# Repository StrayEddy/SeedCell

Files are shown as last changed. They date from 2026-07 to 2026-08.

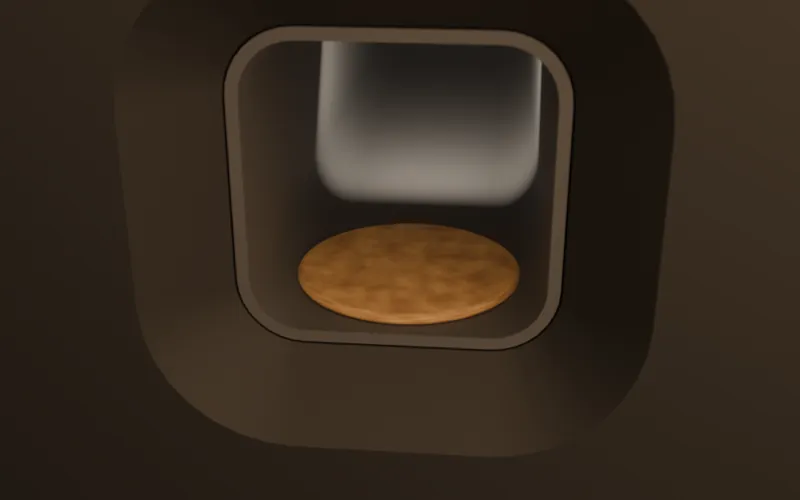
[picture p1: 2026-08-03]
assets/hero-800.webp

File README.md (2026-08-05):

# SeedCell

**🌐 Project site: [strayeddy.github.io/SeedCell](https://strayeddy.github.io/SeedCell/)**

**Autonomous public food infrastructure — the food sibling of [HiveCell](../HiveCell).**

> **Open-source hardware research — uncertified, not a deployable product.**
> SeedCell bakes and serves food to the public from an unattended machine. It is
> **design and simulation only**: no built hardware, no microbiological validation, no
> food-safety certification. **Do not build this to feed anyone.** See [`LICENSE`](LICENSE)
> for the full safety notice and licensing.

A public, autonomous machine that turns long-life dry ingredients into a fresh, warm,
nutritious flatbread on demand, so that **no one goes hungry because they cannot afford
food**. It is not a vending machine — it is closer to a **food syringe**: a sealed machine
that briefly opens, delivers food, then cleans itself.

Design priorities (in order): food safety & hygiene, vandal resistance, reliability, low
maintenance, low energy, low cost, simplicity, long lifetime. It guarantees basic
nutrition — a warm daily survival ration eaten by hand with no packaging — not a meal out.

## Mechanism

**The hot syringe (ADR-0001).** A single heated piston moves inside a fixed heated bore.
Idle, the piston face is the flush public wall. To make food it retracts to open a short
cook chamber; dry blend is metered in and **hydrated by injected water jets — no mixer
blade** (ADR-0006); the piston presses the dough and **conduction-bakes** it against its
heated face (ADR-0007); it advances to flush at the wall, leaving the flatbread standing
proud where a person can take it (ADR-0021); then parks deep
in a sealed zone to **scrape + steam + heat-sterilize + dry** before the next serving
(ADR-0010). The whole cycle is one part translating along one axis — the same syringe bargain
as HiveCell.

The engineering goal is not making food — it is **minimizing food-contact surfaces**. The
design collapses them to essentially one chamber, one transfer, one delivery surface: the
bore wall and the piston face. Everything upstream stays dry (ADR-0012).

## Food

A fortified protein flatbread from whole-wheat + chickpea + lentil flour, a little oil, salt,
water, and a micronutrient premix. Target per serving (`scripts/dosing.py`, first-order):

| Metric | Target | Model |
|---|---|---:|
| Energy | 500–700 kcal | ~571 kcal |
| Protein | 20–30 g | ~26 g |
| Ingredient cost | $0.15–0.25 | ~$0.21 |

Cook thermodynamics + energy in `scripts/cook_energy.py` (~59 Wh/serving bake).

## Safety status

SeedCell makes food for **vulnerable people, unattended, for years**, so food safety is the
first design constraint. Full analysis in [`docs/SAFETY.md`](docs/SAFETY.md); decisions in
[`docs/DECISIONS.md`](docs/DECISIONS.md). The core invariant: **a batch that is not provably
cooked AND served on a provably clean surface is diverted to waste, never to a person.**

Current state — **design + simulation / first-order analysis, no certified hardware:**

| Safety function | Status |
|---|---|
| SF1 Cook lethality (primary) | diverse-redundant fail-safe voter (2× core probe + IR + F-value), serve only on positive proof (ADR-0009) — `[sim]` |
| SF2 Surface sanitation (primary) | scrape + steam + reused-heat sterilize + dry, verify-or-lockout every cycle (ADR-0010) — `[sim/decision]` |
| SF3 Contamination barrier / scraper seal | circular scraper lips wipe the full bore each stroke; drag/residue budget (ADR-0011) — `[cad]` |
| SF4 Burn + pinch guard | touch-safe surface cap + mouth force cap → abort present (H4/H5) — `[sim]` |
| SF5 Motion signalling + soft profile | beacon + soft-start/stop + slow final approach (shared with HiveCell) — `[sim]` |
| SF6 Ingredient integrity / spoilage lockout | dry-storage moisture/temp lockout (ADR-0012) — `[decision]` |

**Biggest open risk:** food **residue + release** is the master variable — it couples the
cleaning method (SF2), the scraper (SF3), the surface + formula (ADR-0008), yet is only
estimated (~1000× range, `scripts/residue.py`). It must be measured on a real baked coupon
before the cleaning design is frozen (ADR-0011). A ~$150–250 bench procedure to do exactly
that — the highest-value next experiment, and a great first contribution — is in
[`docs/residue_bench_test.md`](docs/residue_bench_test.md).

## Software stack

| Tool | Role |
|---|---|
| FreeCAD  | Mechanical design (parametric, source of truth) |
| Godot | Process / food-safety simulation & digital twin |
| Blender  | Rendering & presentation (later only) |
| Git | Version control |

## Layout

- `cad/`     — FreeCAD model (generated by `scripts/build_model.py`)
- `docs/`    — engineering notes, calculations, decisions
- `scripts/` — parametric model + first-order analysis (dosing, cook, residue, sizing)
- `godot/`   — process digital twin + headless self-tests
- `docs/DECISIONS.md` — engineering decision log (read this first)
- `docs/SAFETY.md`   — food-safety + machine-safety analysis
- `docs/ROADMAP.md`  — prioritized roadmap

## Setup

The machine must never serve food that isn't provably safe, so the serve cycle is gated by a
food-safety interlock (`godot/process_interlock.gd`, per `docs/SAFETY.md`). A headless
self-test enforces the core invariant — a raw or unclean batch is never served — and a
pre-push hook blocks pushes if it fails.

After cloning, point git at the hook once:
```sh
git config core.hooksPath .githooks
```
Run the self-tests manually anytime (set `GODOT_BIN` if Godot isn't on `PATH`):
```sh
./scripts/run_selftest.sh
```
Regenerate the CAD model / run the analysis:
```sh
flatpak run --command=freecadcmd org.freecad.FreeCAD scripts/build_model.py
python3 scripts/dosing.py && python3 scripts/cook_energy.py && python3 scripts/residue.py
```

## License & contributing

SeedCell is open-source, licensed by file type: **hardware** (`cad/`, `blender/`,
`renders/`) under CERN-OHL-S-2.0; **documentation** (`docs/`, this README) under CC-BY-4.0;
**software** (`godot/`, `scripts/`) under Apache-2.0. Full texts in [`LICENSES/`](LICENSES/);
the scheme and **safety notice** are in [`LICENSE`](LICENSE). Contributions welcome — see
[`CONTRIBUTING.md`](CONTRIBUTING.md); the most valuable one right now is a real bench
measurement of food residue/release (ADR-0011).

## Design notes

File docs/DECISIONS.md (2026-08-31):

# Engineering Decision Log

Append-only record of significant engineering decisions (an ADR — Architecture
Decision Record — log). Each entry: what we decided, why, and what it rules out.
Newest at the bottom. SeedCell is the food analog of the sibling
[HiveCell](../../HiveCell) project and deliberately reuses its workflow and conventions.

---

## ADR-0001 — Motion principle: the hot syringe (cook-in-bore, eject-through-mouth)
**Date:** 2026-07-31
**Status:** Accepted

**Decision.** SeedCell is a single heated piston moving inside a fixed heated tube
("bore"), directly mirroring HiveCell's true-syringe topology — but the product is a
flatbread ejected through the mouth, not a cavity presented to a person.
- Idle: the piston face sits flush at the mouth (the public wall plane, X=0), sealing
  the machine. The face IS the flush public wall — no separate door or shutter.
- Make: the piston retracts, opening a short cook chamber in the bore; dry blend is
  metered in and hydrated in place; the piston presses the dough into a thin disc and
  bakes it against its own heated face. (*Written as two hot faces; only one exists —
  ADR-0017, open.*)
- Deliver: the piston advances to flush at the wall plane and stops there, leaving the
  finished flatbread standing 8 mm proud where a person can take it (ADR-0021).
- Clean: the piston parks deep in a sealed sterilize zone where its face and the bore
  are scraped, steamed, heat-sterilized and dried before the next serving.

**Why.** Fewest moving parts (one primary piston, one drive) → best reliability, cost,
simplicity — the same reasoning that made HiveCell a syringe. Crucially, it collapses
the **food-contact surfaces to the absolute minimum**: the bore wall and the piston
face — "one chamber, one transfer, one delivery surface" (the stated
design goal). The piston face does quadruple duty (flush wall + cook platen + delivery
surface + cleaning interface), exactly as HiveCell's piston is floor + door + squeegee.

**Rejected alternatives.**
- A — Conveyor/station line (dose → mix → press → griddle → deliver): a bakery in a
  box. Every transfer is another food-contact surface to clean; the opposite of the goal.
- B — Vending of pre-made items: not fresh, needs packaging, not the mission.
- C — Rotary drum / carousel of pans: most mechanism + many pans to clean.

**Accepted costs / constraints.** A few hidden service-side helpers may still be needed
(a mouth die, hydration jets, cleaning stations) — SeedCell will accrete them the way
HiveCell accreted spray rings and a service squeegee. *(2026-08-05: the mouth die was the
first of these to be tested against the rest of the design, and it did not survive — see
ADR-0021. Worth noting that this paragraph predicted accretion and named the exact part
that turned out to be unearned.)* The single-chamber ideal has a
real tension: charging + hydration ports are extra small contact points (see ADR-0006);
tracked, not hidden. Bore/piston dimensions are first-pass (`scripts/build_model.py`).

---

## ADR-0002 — Authoring workflow: code-first FreeCAD scripting
**Date:** 2026-07-31
**Status:** Accepted

**Decision.** The model is authored as git-tracked Python (`scripts/build_model.py`)
run headless via `freecadcmd`. The Python is the source of truth; `cad/SeedCell.FCStd`
is a generated build artifact. The GUI is used only to view/measure, never to hand-edit.

**Why.** Identical rationale to HiveCell ADR-0002 (same author, same toolchain): fast,
diffable, fully parametric, version-controlled, with a headless motion-preview path into
the Godot twin. Reusing the sibling project's proven workflow costs nothing to adopt.

**Regenerate command.**
`flatpak run --command=freecadcmd org.freecad.FreeCAD scripts/build_model.py`

---

## ADR-0003 — Cross-section: round bore (cylinder), not a capsule
**Date:** 2026-07-31
**Status:** Accepted

**Decision.** The bore is a plain circular cylinder; the flatbread is a disc.

**Why.** HiveCell needed a rounded-*rectangle* because a person lies on a flat floor.
SeedCell has no such constraint, so it takes the cylinder HiveCell's ADR-0001 originally
wanted: **no internal corners at all** → the easiest possible full-perimeter scraping
(a single circular lip wipes the entire bore), best hygiene, best vandal resistance, and
axisymmetric heating for an even bake. A disc flatbread is also the most natural hand
food. `boreDia = flatbreadDia + 2·runningClearance`; `pistonDia = boreDia − 2·clearance`.

---

## ADR-0004 — CookBarrel = fixed heated barrel, open at both ends
**Date:** 2026-07-31
**Status:** Accepted

**Decision.** `CookBarrel` is the fixed syringe barrel: a uniform-wall tube, open at the
mouth (X=0, public/delivery) and at the deep service end (X=barrelLength, sterilize +
drive). Its near-mouth band is a heated **griddle zone** (the front cook platen). The
wall carries the small charge/hydration ports (ADR-0006).

**Why.** An open-ended sleeve is the true syringe barrel and keeps each part
independently manufacturable, exactly as HiveCell ADR-0004. Heating only the near-mouth
band (not the whole 330 mm) concentrates thermal mass where the bake happens and where
sterilization heat is reused (ADR-0010). `wallThickness` 8 mm is structural/thermal TBD.

---

## ADR-0005 — Piston: the single heated moving part
**Date:** 2026-07-31
**Status:** Accepted

**Decision.** The `Piston` is a cylindrical plug riding in the bore on a
`runningClearance` (2 mm/side), scraper lips bridging the gap (SF3). Its flat front face
is a **heated cook platen** and, at full advance, the flush public wall. Modelled in the
DEPLOYED/flush pose (face at X=0); the whole mechanism's motion is this ONE part
translating +X by `stroke` — ideal for the digital twin (`godot/process_interlock.gd`).

**Why.** A running fit prevents binding; the lips scrape the bore and separate the public
mouth side from the sealed service side. Depth (`pistonLength` 120 mm) resists tilt/jam
and houses the face heater + its thermocouples (SF1 core probes, ADR-0009). One heated
moving part means one thing to clean and one thing that can fail — the syringe bargain.

**Placeholders.** Solid plug now; the face heater, embedded probes, and lightweighting
are later milestones. `pistonLength`, `runningClearance`, `chargeDepth` are tunable.

---

## ADR-0006 — Hydration by injection, not a mixer blade (mixing with no food-contact mover)
**Date:** 2026-07-31
**Status:** Accepted

**Context.** Research question #2: can mixing/pressing/cooking collapse into one chamber?
A stirring blade or auger would be a food-contact moving part with vanes, a shaft seal,
and crevices — a cleaning nightmare and a reliability risk, the exact thing the syringe
philosophy forbids.

**Decision.** Do the mixing with **fluid, not a blade.** Dry blend is metered into the
bore; then water (+ dissolved oil/salt/fortificant) is **injected as high-shear jets**
through a fixed ring (`HydrationRing`) into the dry powder. The jet turbulence hydrates
and mixes the dough in place. The piston then presses it. No rotating element, no shaft
into the food, no blade to clean — the mixer is a set of nozzles that only ever touch
clean water on the supply side.

**Why.** Removes the single worst food-contact moving part from the machine and keeps the
whole cook in one chamber. Jet hydration of flour is well-understood (continuous dough
systems, spray hydration). Reuses the same nozzle hardware the cleaning cycle wants
anyway (ADR-0010).

**Rejected alternatives.**
- Blade/paddle/auger mixer: food-contact mover + shaft seal + crevices. Rejected.
- Pre-mix a wet batter externally: reintroduces a wet reservoir that spoils and must be
  cleaned — breaks "everything upstream stays dry" (ADR-0012).

**Accepted costs / to verify.** Jet-only mixing may leave dry pockets or need a specific
flour grind / injection sequence; the piston's press adds kneading. The wall ports are
small extra food-contact points (ADR-0001 tension) — they are wiped by the passing seal
each stroke. Dough uniformity + hydration time are bench items (research question #1).

---

## ADR-0007 — Cook: two-sided conduction bake in the one chamber
**Date:** 2026-07-31
**Status:** Accepted

**Decision.** Cook by **conduction between two hot platens** — the heated bore-end/die
and the heated piston face — pressing the thin dough disc between them (a contact
griddle). No separate oven, no hot air, no radiant element in the food space.

> ⚠ **The second platen does not exist (ADR-0017, OPEN).** The "heated bore-end/die" named
> here was only ever a 2 mm contact ring, and ADR-0021 removed it outright. As built, this
> is a **one-sided** bake against the piston face alone. The energy and lethality numbers
> below assume two-sided heating and are therefore optimistic until ADR-0017 is decided.

**Why (quantified, `scripts/cook_energy.py`).** A thin flatbread is ideal for
conduction: at 8 mm thickness heated from both sides at 230 °C, the core clears a 75 °C
kill target in tens of seconds (Fourier analysis), and ~59 Wh/serving covers the bake.
Conduction reuses the *same* hot surfaces that (a) form the bread and (b) get
heat-sterilized during cleaning (ADR-0010) — one set of heated surfaces does forming,
cooking, and sanitizing. That is the single-chamber collapse research question #2 asked
for: **mix (ADR-0006) + press + cook all happen against the piston face and bore, with
no transfer.**

**Rejected alternatives.**
- Convection/impingement oven: hot-air ducting + fan = more surfaces + a fouling air path.
- Radiant/IR or microwave: uneven for a dense legume dough; adds emitters in the food zone.
- Deep-fry / steam-only: oil bath or water bath to maintain, spoil, and clean.

**Accepted costs / to verify.** Contact baking browns the two faces but not edges — fine
for a flatbread; verify crust/cook uniformity and that the core lethality (SF1) is met at
the geometric worst case (thickest/coldest point), not just the mean. The real control is
an accumulated time-temperature lethality (F-value), not a single set-point (ADR-0009).

---

## ADR-0008 — Anti-stick: low-adhesion face + sacrificial dry-flour boundary layer + self-releasing bread
**Date:** 2026-07-31
**Status:** Accepted

**Context.** Research questions #1 and #4: the least-sticky nutritionally-complete
flatbread, and designing the food itself to minimise residue. Dough sticking to the hot
surfaces is the whole hygiene problem: a stuck film cooks onto the platen and smears into
the next serving (H2 cross-contamination).

**Decision.** Attack stickiness three ways at once:
1. **Low-adhesion food-contact surface** — PTFE / seasoned-ceramic-coated stainless on the
   piston face + griddle band. Low work of adhesion so the bread lets go.
2. **A sacrificial dry-flour boundary layer** — the surfaces are dusted with dry flour
   *before* the dry blend + water arrive, so the wet dough contacts a flour film, never
   bare metal. The film bakes into the bread's own crust and **leaves with the bread** —
   like semolina on a pizza peel. The anti-stick consumable is just more of the food.
3. **A lean, self-releasing formula** — keep hydration and fat moderate and let the bake
   dry the crust so the disc *shrinks and self-releases* before the piston even ejects it.

**Why (quantified, `scripts/residue.py`).** A low-adhesion surface + flour boundary layer
drops the release stress and per-cycle residue by ~2 orders of magnitude vs bare hot
steel, into the µg/cm² range — plausibly self-cleanable every cycle. Designing the food
to leave (points 2–3) means the cleaning system (ADR-0010) starts from "almost clean",
not "scrub baked-on dough".

**Rejected / not chosen.** Oil-flood release (a fryer by another name; rancid film to
clean). Aggressive high-hydration dough for a softer bread (sticks hard; trends to the
residue HIGH case). Both revisitable if the bench test allows.

**Accepted costs / to verify.** PTFE/ceramic durability under repeated scraping + 230 °C
+ steam is a hard material spec (couples SF3 scraper aggressiveness). "Self-releasing"
and "µg/cm² residue" are asserted — **measure both on a real baked coupon**
(`docs/residue_bench_test.md`) before freezing the surface, the formula, and the cleaning
method. This is SeedCell's master-variable trap (ADR-0011).

---

## ADR-0009 — SF1 cook lethality is the primary safeguard: never present a batch that isn't provably cooked
**Date:** 2026-07-31
**Status:** Accepted (architecture + fail-safe logic); sensor part numbers + validation TBD

**Context.** SeedCell is HiveCell's mission inverted: HiveCell must never *move* until it
proves a space is empty; SeedCell must never *serve* until it proves a batch is cooked.
Both users are VULNERABLE — a homeless or food-insecure person eating a machine-made
ration daily, with no recourse if it makes them ill. A missed kill-step can cause
foodborne illness at scale. So the PRIMARY safeguard is the cook lethality check, and it
must fail safe: absence of proof of a cook is never "cooked".

**Decision.**
1. **The kill-step is proven, not assumed.** Every serving must reach a validated core
   time-temperature lethality (an accumulated F-value) before it may be presented. The
   gate lives in `godot/process_interlock.gd` (LETHALITY_CHECK → PRESENT or → DIVERT):
   **there is no "serve it anyway" branch.** A batch that fails is diverted to the waste
   chute, never to the mouth.
2. **Diverse-redundant, fail-safe voting** (`godot/cook_lethality.gd`), the direct analog
   of HiveCell's occupancy fusion (ADR-0012 there), inverted to "prove safe":
   - **AND toward safe** — serve only when EVERY channel positively confirms the kill-step.
   - **fault = unsafe** — any channel faulted, out-of-range, or stale reads "not cooked".
   - **diversity** — two independent core thermocouples + a surface pyrometer + an
     independent time-temperature (F-value) integrator, so no single common-cause fault
     can wave a raw batch through.
3. **SF4 mouth guard is separate** — even a perfectly cooked batch is not pushed through a
   hand (pinch) or served scalding (burn); the present stroke aborts if the mouth is
   unsafe (ADR-0011 mechanical, SAFETY.md SF4).

**Why.** No single temperature reading can be trusted for an unattended public food
machine running for years. Diverse redundancy + prove-safe + fault-is-unsafe is the only
way to a high-integrity kill-step. The twin already encodes the LOGIC and self-tests it
exhaustively (`tests/test_cook_lethality.gd`, all 3⁴ vote combinations); this ADR fixes
the architecture and the fail-safe direction.

**Rejected alternatives.**
- Single thermocouple / fixed timer: common-cause blind spots; a stuck probe serves raw.
- Camera / colour "doneness" AI as primary: opaque failure modes, hard to trust for a
  safety kill-step. Auxiliary at most.
- "Cook long enough and assume": no proof; drifts as ingredients/ambient change.

**Accepted costs / to verify.** Cost of 4 diverse channels + a rated controller — justified
by the every-serving vulnerable-user case. Validate F-value targets against a real
pathogen-lethality model for a low-moisture legume flatbread; set the target from food-
safety data, not a guessed 75 °C. Probe placement must read the geometric coldest point.
This is `[sim]` — logic + architecture, no physical probes yet.

---

## ADR-0010 — Cleaning: scrape + steam-sanitize + heat-sterilize + dry, in a sealed service-side chamber
**Date:** 2026-07-31
**Status:** Accepted (architecture + method); sizing, water/energy, sewer + freeze TBD

**Context.** Research question #3: clean every food-contact surface automatically after
each serving. SeedCell's advantage over HiveCell is that the contaminated area is tiny
(one bore + one face) and mostly DRY residue (baked crumbs + a µg film, ADR-0008), not
bodily fluids. The disadvantage: it must reach food-grade sanitation, every cycle, with
no human.

**Decision.** A four-step motion-driven cycle, all on the sealed service side (the piston
parks deep; nothing cleaning-related is on the public face — the HiveCell ADR-0016 lesson):
1. **Scrape (mechanical).** The piston's own circular scraper lips (SF3) wipe the full
   bore perimeter as it retracts — the syringe-native squeegee — pushing dry crumbs to a
   waste path. This alone removes the bulk, because the food was designed to leave (ADR-0008).
2. **Steam / hot-water sanitize** (`SterilizeRing`) — a fixed ring wets + thermally
   sanitizes the parked face and bore band.
3. **Heat-sterilize (nearly free).** The griddle surfaces are ALREADY at ~230 °C from the
   bake; holding them hot dry-heat-sterilizes the food-contact metal between servings at
   no extra heat-up — a genuine advantage of a hot machine (contrast HiveCell, which had
   to reject pyrolysis because its cavity held people and sensors).
4. **Hot-air dry** (`HotAirKnife`) — present the next bread on a dry surface.

**Why.** Dry-designed residue + a full-perimeter scraper + reused bake heat means most
sanitation is mechanical + thermal and essentially free; steam closes the gap. Keeping it
all service-side keeps the public face a plain flush wall (vandal resistance #1).

**Rejected alternatives.**
- Pyrolytic burn-off only: works thermally but wastes heat cycling and can't shift a wet
  film alone. Kept only as the *reused-heat* sterilize step, not a full burn.
- Flood/CIP immersion: asks a scraper seal to hold a water column; water/energy/dry/freeze.
- Chemical disinfectant every cycle (HiveCell's choice for fluids): here the residue is
  cooked starch, not pathogen-laden fluid, so thermal + steam should suffice — avoiding a
  disinfectant consumable AND its H7 chemical-residue-on-food hazard. Revisit only if the
  bench log-reduction proves marginal.

**Accepted costs / to verify.** Material spec: the low-adhesion coating must survive
scraping + 230 °C + steam repeatedly (couples ADR-0008, SF3). Prove the thermal + steam +
scrape log-reduction is enough for a food surface without chemicals (the key bench gate).
Quantify water + drying energy per cycle. Sewer tie for the (small) wash effluent; outdoor
freeze protection. Confirm the scraper actually clears crumbs to waste and not into the
running gap.

---

## ADR-0011 — Residue + release is the master variable (measure it before freezing the design)
**Date:** 2026-07-31
**Status:** Accepted

**Context.** Exactly as seal drag is HiveCell's master lever (their ADR-0011), SeedCell has
ONE number the whole machine hinges on: how much cooked-food **residue** remains on a
food-contact surface after one bake+clean cycle, and how hard the flatbread is to
**release**. It couples SF2 (can the surface self-clean to a safe residual every cycle?),
SF3 (how aggressive the scraper must be — which feeds back into its drag and wear),
the surface material spec (ADR-0008), and whether the self-releasing-bread concept even
holds. `scripts/residue.py` (first principles) brackets it across surface × boundary-layer
× hydration and finds a ~1000× spread (µg/cm² for PTFE+flour vs near-1 mg/cm² for bare steel).

**Decision.** Make **low adhesion a hard requirement** (ADR-0008), and MEASURE residue +
release on a real baked coupon before freezing the surface, the formula, the scraper (SF3),
and the cleaning method (SF2). A ~$150–250 bench procedure to do exactly that is
[`docs/residue_bench_test.md`](residue_bench_test.md) — the highest-value next experiment
and the best first contribution (the direct analog of HiveCell's seal-drag bench test).

**Why (quantified, `residue.py`).** Above a per-cycle residue threshold the design must
*change* (different coating, thicker boundary layer, leaner dough, or add a chemical step —
ADR-0010's rejected option) rather than just resize; below it, thermal+steam+scrape suffices
with no chemical consumable. The measurement is a go/no-go on the whole "no-chemicals,
self-cleaning" claim, just as HiveCell's seal-drag number was a go/no-go on its 2-lip seal.

**Follow-ups.** Once measured, re-run `residue.py` / `actuator_sizing.py`
(`SCRAPER_DRAG_PER_M=<n>`) and revisit ADR-0010 (chemical step?) and SF3 (lip count/interference).

---

## ADR-0012 — Ingredients: dry storage + injection hydration; everything upstream stays dry (SF6)
**Date:** 2026-07-31
**Status:** Accepted

**Decision.** All ingredients are stored **dry** (flours, salt, micronutrient premix) in
sealed hoppers (`DryStorage`); oil is a small sealed reservoir; water is mains. Nothing
wet exists until the injection at hydration (ADR-0006). Dosing is gravimetric/volumetric
augers/valves that meter dry powder into the bore. A spoilage-lockout (SF6) monitors hopper
moisture + temperature and refuses to charge from a wet/spoiled hopper (fail-safe, like a
sensor fault in SF1).

**Why.** Dry storage is shelf-stable for the machine's long unattended fill cycles, doesn't
grow anything, and needs no cleaning — the whole upstream path has zero food-contact
cleaning burden (the README maintenance goal: refill, don't wash). Wetness only ever exists
for the ~2 minutes of a bake, inside the one chamber that cleans itself.

**Rejected alternatives.** Refrigerated wet/perishable ingredients (spoilage, energy, a
cold wet path to clean). Pre-hydrated dough cartridges (packaging + a wet reservoir).

**Accepted costs / to verify.** Dry powders bridge/clog and vary in flow with humidity —
dosing accuracy + anti-bridging is a real mechanism item; gravimetric feedback helps.
Micronutrient premix uniformity at 0.5 g/serving (segregation risk). Hopper moisture-ingress
sealing for an outdoor unit.

---

## ADR-0013 — User identification: privacy-preserving ration check, no biometric database
**Date:** 2026-07-31
**Status:** Accepted (principle); implementation + policy review TBD

**Context.** The mission is "no one goes hungry", but a public machine needs to prevent
one person from draining a day's stock (abuse) while RESPECTING the dignity + privacy of
people who are already vulnerable. Fingerprint scanners and a permanent identity database
are both a hygiene problem (a touched public sensor) and a surveillance problem (a registry
of who is hungry).

**Decision.** No fingerprint scanner, no permanent identity database. Instead: a protected
camera behind armored glass does **on-device, ephemeral** recent-serving recognition — "has
*this* face been served in the last N hours?" — with templates that live only in volatile
memory for a rolling window and are never persisted or transmitted. The default failure mode
is **generous**: ambiguity serves the person (the cost of an extra flatbread is trivial vs
the cost of denying a hungry person). The ration policy (interval, per-day cap) is a tunable,
transparent config, not a judgement about the individual.

**Why.** Prevents gross abuse (stock-draining) with the lightest possible touch on privacy
and dignity, and keeps the public face contactless (hygiene + vandal resistance). Erring
generous is consistent with the mission — SeedCell rations to protect *supply for everyone*,
not to police individuals.

**Rejected alternatives.** Fingerprint / touched biometric: hygiene + dignity + a durable
registry. Cloud identity / accounts: excludes the unbanked/undocumented — the exact people
the machine is for. Payment: excluded by the mission (it's free).

**Accepted costs / to verify.** On-device ephemeral recognition accuracy + fairness across
skin tones, occlusion (hoods, masks), and lighting — a real ML + ethics review item; bias
here directly harms the vulnerable. Legal review of even ephemeral biometrics per
jurisdiction. Anti-spoofing vs the generous default (accept some gaming as the price of
dignity). Consider a no-camera fallback (simple time-token) where camera use is unacceptable.

---

## ADR-0014 — CAD → twin / render export conventions
**Date:** 2026-07-31
**Status:** Accepted

**Decision.** `scripts/export_godot.py` (later) writes one OBJ per part to `godot/models/`
plus `seedcell.json` (stroke, timings), baking to Godot space at export: scale ×0.001
(mm→m) and rotate −90° about X (FreeCAD Z-up → Godot Y-up), i.e. (x,y,z)→(x,z,−y). The +X
motion axis is preserved, so the whole cycle is a single −X/+X translation of the Piston
node. Same convention as HiveCell ADR-0006, so the two twins share tooling.

**Rule.** Any new part added to `build_model.py` must be added to `PARTS` in the export
scripts and (if it moves) wired in the Godot scene.

---

## ADR-0015 — SF1 kill-step target: 7-log Salmonella as an F-value, not a core temperature
**Date:** 2026-08-03
**Status:** Accepted (target + model); challenge-study validation and probe placement TBD

**Context.** ADR-0009 fixed the *architecture* of the cook-lethality safeguard — diverse
channels, AND-toward-safe, fault-is-unsafe — but left the actual criterion as an
acknowledged guess: "core reaches 75 °C". That is not a kill-step. It names a temperature
and says nothing about how long it is held, so it cannot distinguish a core that touched
75 °C for a millisecond from one held there for a minute; and it assigns no value at all
to a cook that stalled at 68 °C. The `ft_integrator` channel had no physics behind it —
it was a boolean somebody else had to set.

**Decision.**
1. **The criterion is an accumulated F-value, not a set-point.** Lethality accrues at
   `rate(T) = 10^((T − T_ref)/z)` and `F = ∫ rate dt`, i.e. equivalent seconds held at the
   reference temperature. Implemented in `godot/lethality_model.gd`.
2. **Reference organism: *Salmonella* spp.**, the controlling vegetative pathogen for
   cereal and legume flours. *E. coli* O157:H7 is less heat-resistant and is covered by
   the same margin. The dough core is hydrated during the bake, so moist-heat resistance
   applies.
3. **Target: 7-log reduction**, matching the most stringent common regulatory cooking
   standard. Justified by the vulnerable-user case already argued in ADR-0009.
4. **Constants are fitted to the FDA Food Code 3-401.11 table**, which encodes that
   7-log reduction in two rows — 63 °C/3 min and 66 °C/1 min. Fitting both gives
   `z = 3/log₁₀(3) = 6.29 °C`, and the model reproduces the table exactly rather than
   approximating it. **Target: F₇₀ ≥ 13.9 equivalent seconds.**
5. **A 60 °C accumulation floor.** Below it, lethality credit is discarded rather than
   integrated.
6. **Integrate the coldest point**, never a mean and never the platen: `CookLethality.coldest()`
   takes the lowest core probe, and an empty probe set returns NAN, which reads as a fault.
7. **F is per-batch and never carried across one** (`new_batch()`), and a single
   implausible sample latches the batch suspect no matter how much F was banked.

**Why the floor (6) is a safety rule, not a numerical convenience.** The model is happy to
accrue lethality at 55 °C, and that is mathematically correct — but reaching the target
purely by dwelling there takes ~80 minutes sitting in the bacterial growth zone. Without a
floor, a batch that was never really baked, just left warm, would eventually be declared
cooked. Refusing sub-60 °C credit makes a marginal cook read as a *failed* cook, which is
the direction that diverts to waste.

**What this does NOT cover.** ***Bacillus cereus* spores**, endemic to cereal and legume
flours, are not killed by any bake this machine can perform — spore D-values are minutes at
retort temperature. Their control is not lethality but **time**: serve immediately, never
hold warm. This is a distinct hazard and belongs in SAFETY.md, not in the F-value.

**Consequence — the margin is enormous, and that is the point.** A hydrated core plateaus
near 100 °C, where lethality accrues ~250,000× faster than at the 70 °C reference:
`scripts/cook_energy.py` shows the target cleared at ~24 s and a nominal 90 s cycle banking
~2.6×10⁵ times the requirement. The F-value is not there to constrain the good cook. It is
there to catch the **failed** one — a cold core, a truncated cycle, a dead probe — and to
make "cooked" a quantity a channel can positively prove rather than assert.

**Rejected alternatives.**
- *Keep a core set-point (75 °C, 85 °C, …)*: silent on hold time; the blind spot above.
- *A round literature z of 6.0 °C*: undercuts the Food Code's own 66 °C row by 5% (demands
  57 s where the table says 60 s), i.e. lenient against the regulation it claims to encode.
- *Low-moisture (low-aw) Salmonella resistance data*: far more conservative, but wrong
  physics for a hydrated core; it would be conservatism bought by modelling the wrong thing.
- *Fixed bake timer*: no proof; drifts with ambient, ingredient and platen condition.

**Accepted costs / to verify.** The constants are regulatory and literature values for a
design model, **not a validated process**: a served product needs its own challenge study
(SAFETY.md "Open items", ROADMAP #10). Probe placement must be shown to read the true
geometric coldest point, otherwise the whole integral is measuring the wrong place. The
`CORE_PLATEAU_C = 100 °C` cap in `cook_energy.py` is a modelling assumption about free
water, conservative but unmeasured. Asserted by `godot/tests/test_lethality_model.gd`.

---

## ADR-0016 — SF7 bake→serve hold: *Bacillus cereus* is controlled by time, not heat
**Date:** 2026-08-03
**Status:** Accepted (control + logic); the hold budget is a facility-level parameter

**Context.** ADR-0015 set the SF1 kill-step and, in the same breath, named the hazard it
cannot reach. *B. cereus* is endemic to cereal and legume flours; its **spores survive any
bake this machine can perform** (spore D-values are minutes at retort temperature, against
a bake measured in seconds), so no accumulated F-value touches them. Worse, the emetic
toxin (cereulide) is **heat-stable** — once it has been produced, re-baking cannot undo it.
A machine that proved lethality perfectly and then let the bread sit would still make
people ill, and SF1 would report everything was fine.

**Decision.**
1. **The control is time, not heat.** A batch has a bounded budget between end-of-bake and
   collection; past it, it is waste. `godot/spore_hold.gd`, gate in `process_interlock.gd`.
2. **The clock is temperature-gated, not wall-clock.** Only time spent **below 60 °C**
   accrues. Above that, outgrowth is suppressed and the batch ages for free.
3. **60 °C is deliberately the same number as `LethalityModel.T_FLOOR`** — one threshold
   for "where biology stops", used as a floor for lethality credit in ADR-0015 and as a
   ceiling for risk accrual here. It also sits at the top of the conventional hot-hold
   band (57–60 °C), so it is defensible from both directions.
4. **Default budget 15 minutes** (`DEFAULT_MAX_HOLD_S = 900`), far tighter than the
   4-hour regulatory ceiling for time-as-a-public-health-control. **This is a
   facility-level parameter** in the same class as the formula and the ration policy: the
   device enforces it, it does not choose it.
5. **A dead thermometer accrues risk time rather than pausing the clock**, and latches the
   batch unprovable.
6. **The clock starts at end-of-cook, not at PRESENT** — risk accrues wherever the batch
   waits, including through an abort that never reaches the mouth.

**Why 15 minutes and not 4 hours.** SeedCell bakes **on demand**: the nominal bake→collect
interval is on the order of ten seconds, so 15 minutes is already ~90× the normal case. A
batch that exceeds it has not been *waiting*, it has been **stuck** — a jam, an aborted
delivery, a slow clean — and a stuck batch is precisely the one that must never be handed
to anyone. Spending the regulatory maximum here would buy nothing operationally and give
away the entire safety margin.

**Why a dead sensor must not pause the clock (5).** The intuitive failure handling — "no
reading, don't accrue" — is exactly backwards. A failed thermometer is *correlated* with a
machine that has stopped attending to the batch, so it is the moment a batch is most likely
to be sitting forgotten. Pausing the clock there would grant unlimited holding time in
precisely the fault where it is least deserved.

**Consequential fix.** Wiring the gate exposed an accounting gap that predates it: an abort
mid-delivery (SF4 pinch/burn trip) fell through `RETRACT → CLEAN` and was silently scraped
away, counted as neither served nor wasted. Both abort paths now condemn the batch and
route through `DIVERT`, so **served + wasted accounts for every batch made**. Asserted by
`tests/test_spore_hold.gd` scenario S6.

**Rejected alternatives.**
- *Wall-clock timer from end-of-bake*: condemns a batch still sitting hot in the bore, and
  gives a fast-cooling batch the same budget as one held hot. Wrong physics, both ways.
- *Rely on the SF1 kill-step*: cannot work — spores survive it by orders of magnitude.
- *Re-bake a held batch instead of discarding it*: cereulide is heat-stable; a re-bake
  sterilises the evidence, not the toxin.
- *Hot-hold indefinitely above 60 °C*: technically suppresses outgrowth, but bakes the
  product to leather and burns standby energy for a machine whose whole premise is
  on-demand. The bounded budget is cheaper and simpler.

**Accepted costs / to verify.** The budget is a policy number, not a measured one — a
challenge study on the real product should confirm 15 min at ambient is comfortably inside
the safe envelope. The guard needs a batch thermometer; it reuses the delivered-surface
sensor the SF4 burn guard already requires, so no new hardware. **Not covered:** an
uncollected batch left presented at the mouth — that needs a collection sensor and an
`AWAIT_COLLECT` state, which is separate work (ROADMAP).

---

## ADR-0017 — Retractable heated anvil, service-side, at ≥850 mm depth: the second platen
**Date:** 2026-08-04 (reframed 2026-08-05 after ADR-0021; decided 2026-08-11)
**Status:** Accepted.

> **Read the second addendum first (2026-08-05).** ADR-0021 removed the mouth die, so the
> geometry the body of this ADR argues about no longer exists. The *problem* is unchanged and
> slightly larger; the options below are re-scored at the end.

**Context — how this surfaced.** Drawing the CAD 1:1 for `docs/cell_anatomy.svg` forced the
question "what closes the mouth while the machine is cooking?", and the answer is: nothing.

Three things that are each individually reasonable do not hold together:
- `MouthDie` is an **annulus** — a Ø180 ring with a **Ø156 bore** (`build_model.py`). It has to
  be open, because that is how the bread comes out and how the die shears its rim.
- **ADR-0007** bakes by conduction between "the heated bore-end/die and the heated piston face".
- **ADR-0001** states the piston face *is* the flush public wall — "no separate door or shutter".

But the piston sits **retracted 60 mm** through CHARGE → HYDRATE → COOK. For that whole time —
roughly 90 s per `cook_seconds` — the mouth is an **open Ø156 hole into a 230 °C chamber**, on a
public street, with loose dry blend and then injected water inside it.

**What it contradicts.** Hazard **H6** (contaminant ingress / tampering, S=4) lists its mitigation
as "mouth flush + sealed except during present". That is currently false. H6's likelihood score
was set on the assumption of a sealed mouth, so the risk number is optimistic until this is
resolved. This is a **stated mitigation the geometry does not deliver**, which is a different and
worse class of problem than an unimplemented item.

**Second, related problem.** The CAD provides no workable hot platen at that end either. ADR-0007's
"bore-end/die" hot face is, geometrically, only the **2 mm annular ledge** between die ID (156) and
bore ID (164). A 2 mm ring cannot conduction-bake a Ø160 disc. Whatever closes the mouth probably
has to be the lower platen as well, so these two are one decision, not two.

**Options (trade-offs only — not a decision).**

1. **A mouth closure — shutter, iris, or rotary valve at X≈0.** Solves both problems at once if the
   closure is heated: it becomes the missing platen. *Cost:* directly contradicts ADR-0001, and adds
   a moving part in the food path that must itself be cleaned every cycle — precisely the thing the
   syringe topology exists to avoid. It would need its own entry in the SF2/SF3 story.
2. **Bake deeper, then transfer.** Move the cook chamber away from the mouth against a heated anvil
   further down the bore. *Cost:* breaks "one chamber, one transfer, one delivery surface", the
   central claim of ADR-0001, and adds a second food-contact zone to sanitize.
3. **Accept the opening; defend H6 by other means.** Mouth obstruction/presence sensing with
   divert-on-detect, plus the argument that a 230 °C chamber is hostile to what gets pushed into it.
   *Cost:* structurally cheapest and changes no geometry, but it is the weakest answer to deliberate
   tampering, and "the chamber is hot" does nothing about a fluid poured in during HYDRATE.
4. **Shrink the exposure window.** Charge and hydrate fast, then press immediately so the Ø160 dough
   disc itself plugs the Ø156 die within a second or two. *Cost:* reduces but does not eliminate the
   window, and it makes the bread's public face the seal — its outer surface is then exposed to
   street air for the whole bake, which is its own hygiene question.

**Recommendation (a recommendation, not the decision):** 3 + 4 together are the only combination
that changes no geometry, and they are worth costing first because 1 and 2 each break a load-bearing
ADR. But if the honest answer is that a public machine cannot cook with its mouth open, then option 1
is the real fix and ADR-0001's "no door" should be amended rather than defended.

**Whatever is chosen** must update: `scripts/build_model.py`, `docs/cell_anatomy.svg` (drawn 1:1, so
it moves with the model), H6's mitigation and score in SAFETY.md, and — if the cycle timing changes —
`cook_seconds` and the interlock states.

### Addendum, 2026-08-04 — two corrections from drawing the mouth at 8:1

Redrawing `docs/cell_anatomy.svg` with a proper mouth detail (views A/B and the 8:1 die-corner
section C) turned up two things. Neither changes the recommendation; the second changes how big
the problem is.

**(a) The ledge is 4 mm, not 2 mm — but the *contact* really is 2 mm.** Above, this ADR calls the
bore-end platen "the 2 mm annular ledge between die ID (156) and bore ID (164)". That gap is
(164−156)/2 = **4 mm** radially. The 2 mm is a different number: it is how far the Ø160 disc
overlaps the Ø156 die, (160−156)/2. Since the remaining 2 mm of ledge is the running clearance,
which the disc never touches, the *effective* hot ring is 2 mm after all. The arithmetic was
wrong and the conclusion was right, which is worth writing down rather than quietly fixing.

**(b) There is no PRESS step anywhere, so "where is the piston during the bake?" is undecided —
and it is the biggest single lever on this decision.** Three artefacts disagree:
- `scripts/build_model.py` describes `chargeDepth` as "the piston retract that opens the
  charge/**cook** chamber" — 60 mm open, for the cook.
- **ADR-0007** presses the dough to 8 mm between two platens, which puts it against the die.
- `godot/process_interlock.gd` runs CHARGE → HYDRATE → COOK **without moving the piston at all**;
  `progress` is untouched until PRESENT. The cycle strip in the drawing, meanwhile, has always
  drawn the bake already pressed up.

This is not a documentation tidy-up. **If the press happens before the bake, the Ø160 dough disc
plugs the Ø156 die for the whole ~90 s cook**, and the open-mouth window collapses from ~90 s to
the few seconds of CHARGE + HYDRATE. That is most of option 4, for free, and it materially
improves how option 3 + 4 scores against options 1 and 2 — which are the two that cost a
load-bearing ADR. Deciding the press order is therefore a **prerequisite** to deciding this ADR,
not a consequence of it.

It does not make the problem vanish: a few seconds of open mouth is still an opening, the bread's
own face becomes the seal (with its own hygiene question, already noted under option 4), and
**(a) is untouched** — a 2 mm contact ring still cannot bake a Ø160 disc, whenever the press
happens. The platen half of this ADR stands on its own.

### Second addendum, 2026-08-05 — the die is gone; this is now "what belongs at the bore end?"

**ADR-0021 removed `MouthDie` entirely.** The reasoning is there, not here; what matters for this
decision is that the geometry above is obsolete in a specific way:

- **There is no Ø156 aperture any more.** The bore ends in a plain open Ø164 cylinder at the wall
  plane. "Close the Ø156 hole" was the wrong framing — the question is what, if anything, occupies
  the bore end at all.
- **The 2 mm platen is not merely inadequate, it is absent.** Addendum (a) established that the
  ring gave 2 mm of usable contact. That ring is gone, so the bake is now unambiguously
  **one-sided**: the piston face is the only platen. ADR-0007's "conduction between two hot
  platens" currently describes a machine with one.
- **The exposure window is unchanged (~9 s, per ADR-0019)**, but its *character* changed. The
  dough no longer plugs a narrower ring; it sits in a full-bore opening with a 2 mm annular gap
  around it, and its outer face is flush with the street rather than recessed inside a 10 mm
  channel.
- **One thing got better:** the delivery. The bread now stands 8 mm proud of a flush wall instead
  of recessed 2 mm inside a hole. Whatever is chosen below **must not undo that** — which is a new
  constraint the original four options were never scored against.

**Re-scoring the four options against the new geometry.**

1. **A heated closure at X=0 (shutter / iris / rotary valve).** *Strengthened.* It was always the
   only option that answers both halves at once, and with the die gone it is now the only source
   of a second platen of any kind. Its cost is unchanged and still severe: it contradicts
   ADR-0001's "no door", and it puts a moving part in the food path that must itself be cleaned
   every cycle — the exact thing the syringe topology exists to avoid. **It must also not
   re-recess the serving**; a closure that retracts clear of the aperture keeps the 8 mm-proud
   delivery, one that sits proud of the wall throws it away and re-creates the die's ergonomic
   defect under a different name.
2. **Bake deeper against an internal anvil, then transfer.** *Unchanged, still expensive.* Breaks
   "one chamber, one transfer, one delivery surface" and adds a second food-contact zone to
   sanitize. But note it now has a distinct advantage it did not visibly have before: an internal
   anvil is **inside the cleanable volume**, so it is the only way to get a second platen without
   putting a mechanism at the public face.
3. **Accept the opening; defend H6 by other means** (obstruction sensing + divert-on-detect).
   *Unchanged as a closure answer, and it was never a platen answer.* On its own it now leaves the
   bake one-sided, so it can only ever be half of a solution.
4. **Shrink the exposure window by pressing early.** *Already banked* — this is ADR-0019, done. It
   contributes nothing further and is no longer an open option.

**Where this leaves the recommendation.** The original text preferred "3 + 4 together" because
they changed no geometry. 4 is now spent, and 3 alone leaves a one-sided bake — so **the cheap
combination no longer adds up to an answer.** The live question is whether the second platen comes
from a *closure at the face* (option 1, mechanism in public, must preserve the 8 mm-proud
delivery) or from an *anvil deeper in the bore* (option 2, mechanism in the clean zone, costs a
transfer). That is a genuine fork, and it is the thing to decide next.

**A fifth criterion, newly explicit: can a person actually take the bread?** Options 1–4 were
scored on hygiene, hazard, and cost, and none of them asked this. The die's removal exposed that
the delivery had been ergonomically bad for the whole life of the project without anyone scoring
it. Any candidate must now be judged on the reach it leaves the person, not only on what it does
for H6.

### Decision addendum, 2026-08-11 — option 2: retractable heated anvil, service-side

**Decision: option 2.** A retractable heated anvil sits inside the bore, on the service side,
at a depth of **≥ 850 mm from the public face**. The piston presses dough against it to bake;
after baking the anvil retracts (into the service/clean zone, never exposed to the public);
the piston then advances the full remaining stroke to deliver the bread 8 mm proud of the wall.

**Why 850 mm.** ISO 13857 (safety distances — reach through openings) Table 2: for an opening
through which the whole arm can pass (opening dimension > 120 mm), the safety distance to any
hazard zone is 850 mm. The bore is Ø164, well above 120 mm, so a person standing at the wall
can reach 850 mm in. The anvil — a 230 °C surface — must be beyond that distance.

**Why this option and not option 1 (closure at the face).**
- ADR-0001's "no door or shutter at the public face" is a load-bearing architectural choice,
  not an aesthetic one: any mechanism at X=0 is in the food path, must be cleaned every cycle,
  is exposed to vandalism, and re-introduces the exact complexity the syringe topology exists
  to avoid. That cost did not change.
- Option 2's previously listed cost — "breaks one chamber, one delivery surface" — is the
  honest cost, but it is the smaller one. The cleaning story for the anvil face is no harder
  than cleaning the piston face: it is inside the sealed service volume, reached by the same
  steam/heat cycle (ADR-0010), and it never crosses the public face.
- The 850 mm depth requirement means the anvil is **unreachable from the street by any person**,
  which is a stronger H6 mitigation than a closure at the face: there is nothing to bypass,
  nothing to tamper with, and the hot surface is geometrically inaccessible.
- ADR-0001 is preserved: the bore still ends in a plain open cylinder at X=0 (per ADR-0021),
  with no mechanism at the public face. The bread — not a mechanism — is the only thing that
  protrudes.

**What this closes.**
- ADR-0007's two-sided conduction bake is restored: piston face (hot) + anvil face (hot).
- H6's stated mitigation ("mouth sealed except during PRESENT") is now geometrically true:
  during COOK the dough disc plugs the bore mouth (ADR-0019), and the hot anvil is ≥850 mm in.
- The bore-geometry block is lifted; the bore can now be frozen once the anvil retraction
  mechanism and the total bore depth are decided.

**What this opens (required follow-up work).**
- **Bore length.** The bake position is at ≥ 850 mm depth (anvil face). The piston must travel
  from there to X=0 (wall) for delivery — a stroke of ≥ 850 mm. Total bore depth = bake depth +
  piston body length + actuator clearance. This must be checked against the assumed wall depth.
- **Anvil retraction mechanism.** Not decided here: lateral slide, axial retraction toward the
  service plant, or hinge. Whichever is chosen must keep the anvil inside the sealed service
  volume at all times and must not create a new pinch geometry in the bore.
- **Anvil as a food-contact surface.** The anvil face contacts dough every cycle and must fit
  into SF2/SF3's scrape + steam + heat-sterilize + dry cycle (ADR-0010). Its geometry must be
  compatible with the piston scraper lips (SF3) passing over it, or it must retract fully before
  the cleaning stroke begins.
- **Piston temperature at delivery.** The piston face is hot during baking; it advances through
  air to deliver. SF4's burn guard already tracks the accessible bread-surface temperature — the
  bread is what a person touches, not the piston face (which is at the wall plane, behind the
  bread). This is an accepted, tracked risk, not an oversight. If thermal modelling shows the
  bread face is too hot at delivery, the fix is a longer advance dwell or a piston-face cool-down
  step before PRESENT — both are interlock states, not geometry.
- **`godot/process_interlock.gd`** needs two new interlock states: BAKE (press + cook against
  the closed anvil) and OPEN_ANVIL (anvil retracts before the piston advances to PRESENT).
- **`scripts/build_model.py`** needs the anvil geometry and a `bakeDepth` parameter (≥ 850 mm).
- **`docs/cell_anatomy.svg`** needs to be redrawn showing the bake pose (piston pressed against
  anvil at depth) and the delivery pose (anvil gone, piston at X=0, bread proud).
- **`docs/SAFETY.md`** H6 mitigation must be updated: "bore depth ≥ ISO 13857 reach distance
  (850 mm for Ø164 opening); no mechanism at public face (ADR-0001/ADR-0021)".
- **Component tree** (bottom of this file) must be updated to add the anvil and its drive.

**Rejected alternative: option 1 (heated closure at the face).** See above. The cost —
a mechanism in the food path on the public face — is disqualifying given ADR-0001. Not
revisited unless the bore-depth constraint turns out to be infeasible for the wall geometry.

---

## ADR-0018 — A serving is not served until it is taken: SF8 collection proof
**Date:** 2026-08-04
**Status:** Accepted (sensor principle + gate logic); the sensor part and the window length
are commissioning choices

**Context.** ADR-0016 closed the bake→collect interval and, in the same breath, named what it
could not reach: *"an uncollected batch left presented at the mouth — that needs a collection
sensor and an `AWAIT_COLLECT` state."* Until now the interlock did not model collection at
all. It incremented `served` the instant the present stroke reached full extension and
retracted immediately — i.e. it **assumed collection was instantaneous and always
successful**. Three separate problems hide inside that one assumption:

1. **Accounting.** "Presented" is not "served". `served` is the twin's liveness measure —
   the thing that stops a trivially-frozen machine from passing its own safety tests — and it
   was measuring *that the piston moved*. Worse, the ration policy (ADR-0013) debits a person
   for a serving; debiting someone for bread they never received is a real harm to exactly
   the population this machine exists for.
2. **Exposure.** Waiting for a person to take the bread holds the mouth open. Modelling the
   wait honestly *creates* an open-mouth window that must then be **bounded**, or a machine
   nobody came back to sits open to the street (H6).
3. **Re-entry.** An uncollected batch has stood in public air, possibly handled, before the
   piston withdraws it back through the bore. It must be condemned, not re-offered.

**Decision.**
1. **New `AWAIT_COLLECT` state.** The stroke ends by *holding the batch out*, not by
   declaring victory. `served` increments in exactly one place (`_hand_over()`), reached only
   from a proven collection.
2. **Collection is a TRANSITION, not a level.** The guard requires the face to be seen
   **carrying** the batch and only *then* seen **empty**. This is the whole integrity
   argument: a sensor stuck at "empty" never arms and so can never manufacture a phantom
   serving; a sensor stuck at "occupied" never sees the transition. Both stuck failures run
   the window out and send the batch to waste — the direction every other guard here fails in.
3. **The window bounds the whole delivery** (stroke + wait), default **120 s**. On expiry the
   batch is condemned: withdraw, `DIVERT`, count as waste. No retry, and nothing is left lying
   at the die.
4. **The window is not a food-safety number, and is deliberately nested inside SF7's.**
   120 s against a 900 s hold budget: whichever expires first condemns the batch, so SF7
   always dominates and the collection window can never extend a batch's life. What it bounds
   is *exposure* (H6) and *availability* — how long one person who walked away can hold the
   machine out of service for the next.
5. **Collection is accepted at any point in the delivery**, including mid-stroke. If the
   bread is lifted off the face on its way out, the correct response is to stop pushing and
   withdraw — not to keep driving an empty hot face out into the mouth.
6. **SF4 splits across the wait.** The **pinch** cap deliberately does *not* gate
   `AWAIT_COLLECT`: the piston is stationary and generates no crushing force, and a hand at
   the mouth is the *intended* event — gating the wait on contact force would condemn
   batches for being collected. The **burn** cap still does gate it: if the presented
   surface stops being touch-safe, withdrawing it takes the hot thing out of reach, and
   that is the protective move. SF7 also keeps running through the wait.
7. **The sensor is loss-of-mass on the actuator force channel** that SF4's contact cap
   already requires — no new hardware, same as SF7 reusing the burn guard's thermometer.

**Why withdrawing a street-exposed batch back through the bore is acceptable.** It looks like
a contamination path into the machine, and it would be one — except that `DIVERT` is *always*
followed by `CLEAN` + `CLEAN_VERIFY`, and no charge can begin until that verification passes
(SF2). The recovery is therefore free: it reuses the gate that already lets the machine bake
at all. Leaving the batch at the die instead would be strictly worse — food outside the
cleanable volume, blocking the next delivery.

**Why there is no `suspect` latch (unlike SporeHold).** SF7 integrates *time*, so a blind
interval destroys information permanently and must be assumed dangerous — hence its latch.
SF8 reads a *state that persists*: a sensor that faults and recovers can still see the face,
and the truth is unchanged. A blind interval costs only the clock that runs through it, and
running that clock out already means waste. Copying SF7's latch here would have been
cargo-culted rigour, not rigour.

**Rejected alternatives.**
- *Beam-break across the mouth aperture*: sees a **hand**, not a batch. It cannot distinguish
  "took the bread" from "reached in and left", which is precisely the case that matters.
- *Treat "face empty" as collection (level, not transition)*: one stuck-open sensor then
  reports a full day of phantom servings while dropping bread on the pavement — and, via
  ADR-0013, debits every one of those people.
- *Re-present an uncollected batch to the next requester*: it has stood in public air and may
  have been handled. Serving it would trade the machine's central promise for one flatbread.
- *No timeout — wait indefinitely for collection*: hands H6 an unbounded open mouth and lets a
  single person who walked away deny service to everyone behind them.
- *Keep counting `served` at full extension and add the sensor later*: leaves the liveness
  measure — the one that certifies the safety tests aren't vacuous — measuring the wrong event.

**Accepted costs / what this does NOT close.**
- **Retracting while a hand is at the mouth is still unguarded.** This is pre-existing (the
  old code retracted immediately after a completed push, when a hand is *most* likely to be
  there) and is not made worse here, but `AWAIT_COLLECT` is where it becomes visible. Closing
  it needs the SF4 mouth-presence sensor plus a bounded "wait for clear before withdrawing" —
  ROADMAP item 8, tracked there explicitly.
- 120 s is an engineering judgement about dignity and throughput, not a measured number; it
  should be revisited from real siting observation (someone slow, encumbered, or unsure).
- The guard proves the batch **left**. It does not prove **who** took it — that is ADR-0013,
  and deliberately stays separate.

**Implementation.** `godot/collection_guard.gd` + `godot/tests/test_collection.gd`;
`AWAIT_COLLECT` + `_hand_over()` + `mouth_open()` in `godot/process_interlock.gd`. SAFETY.md
gains **H11** and **SF8**. The accounting invariant from ADR-0016 — *served + wasted accounts
for every batch made* — is re-asserted across the new state (scenario S4).

---

## ADR-0019 — Press before bake: the piston closes the mouth from the inside before COOK, not during it
**Date:** 2026-08-04
**Status:** Accepted (twin logic + CAD comments updated; force/power sizing corrected). Does
**not** decide ADR-0017 — it resolves the prerequisite ADR-0017's addendum named, and narrows
the number that decision will be made on.

**Context.** ADR-0017's 2026-08-04 addendum found that three artefacts disagreed on where the
piston sits during CHARGE/HYDRATE/COOK: `build_model.py` implied the piston stays retracted for
the whole "charge/cook chamber"; `godot/process_interlock.gd` ran CHARGE → HYDRATE → COOK
without moving the piston at all (silent, not a decision); and the anatomy drawing's cycle strip
had always drawn the bake already pressed up. The addendum flagged this as a prerequisite to
deciding ADR-0017, because pressing before the bake — instead of during or after it — collapses
the open-mouth exposure window from the ~90 s cook to the few seconds of CHARGE + HYDRATE.

**It turns out this was already decided, just not implemented.** Two Accepted ADRs already say
so in prose:
- **ADR-0006**: "Dry blend is metered into the bore; then water ... is injected ... **The piston
  then presses it.**" — press comes after hydrate, as a distinct step.
- **ADR-0007**: "mix (ADR-0006) + press + cook all happen against the piston face and bore, with
  no transfer" — press is between mix and cook, and cook does not move the piston again.
- `scripts/cook_energy.py`'s cook-time/lethality/energy model already assumes
  `THICKNESS_MM = 8.0  # pressed flatbread thickness (two-sided heating)` for the *entire* bake
  — it was never modelling an open, unpressed charge cooking.

So the twin's silence and the CAD comment's wording were the bugs, not an open design question.
This ADR is the paper trail that makes that explicit and fixes the artefacts that drifted.

**Decision.**
1. **New `PRESS` state** in `godot/process_interlock.gd`, between HYDRATE and COOK: the piston
   advances from the open charge/hydrate position (`chargeDepth` retracted, 60 mm) to flush
   (X=0). Timed like CHARGE/HYDRATE (`press_seconds`, no position tracking — the twin only
   integrates `progress` for the PRESENT↔RETRACT delivery stroke, ADR-0018's territory; charge↔
   flush travel is a separate axis this twin does not model continuously).
2. **The piston stays flush through the whole COOK.** Flush is the same X=0 pose already used
   for IDLE and for the end of PRESENT — COOK does not get its own position, it reuses this one.
   This is what makes the Ø160 dough disc plug the Ø156 die for the bake: the bread's own
   pressed face becomes the seal, per ADR-0017 option 4.
3. **`press_seconds := 4.0`**, matching `PRESS_S` in `scripts/actuator_sizing.py` — the forming
   stroke duration that script already assumed for force/power sizing. Twin and sizing model now
   cite the same number instead of coincidentally agreeing.
4. **`build_model.py`'s `chargeDepth` comment corrected**: "opens the charge+hydrate chamber",
   not "charge/cook chamber" — COOK never happens at that retracted position.

**Why (quantified).**
- **Exposure window, before vs after:** CHARGE (3 s) + HYDRATE (2 s) alone was already the
  addendum's estimate; adding the press motion itself (4 s, since the mouth is not plugged until
  the disc reaches the die) gives **~9 s** of open mouth per cycle, against the previous **~90 s**
  (the full `cook_seconds`) — a ~10x reduction. This is most of ADR-0017 option 4's benefit, for
  the cost of writing down a decision that was already implied.
- **Chamber sizing sanity check:** the open charge/hydrate chamber is bore ID (164 mm) over
  `chargeDepth` (60 mm) ≈ 1.27 L. A 220 g dough charge at 700 kg/m³ (`cook_energy.py`'s `RHO`) is
  ≈ 0.31 L — about a quarter of the open volume, so there is headroom for the hydration jets to
  work before the press closes on it; nothing about volume forces a different retract depth.
- **`actuator_sizing.py` was sizing the press stroke wrong.** It computed press-stroke velocity
  from the *full* `stroke` param (`chargeDepth + sterilizeStow` = 210 mm) instead of the actual
  press travel, `chargeDepth` alone (60 mm) — the 150 mm `sterilizeStow` leg belongs to
  PRESENT/RETRACT, not to closing the charge chamber. Fixed (`close_travel`, was `stroke`).
  Corrected numbers at `PRESS_S = 4.0 s`: **15.0 mm/s** (was 52.5), **32.6 W** (was 114.2),
  **0.036 Wh/press** (was 0.127) — the forming force (1088 N, unchanged, it doesn't depend on
  travel distance) is still what sizes the actuator; the old numbers overstated the press's power
  and energy budget by ~3.5x, though the design-driving force number was never wrong.

**Rejected alternative.**
- *Leave the piston retracted through COOK* (what the twin's silence and the drawing's stale
  FLAG 2 both, by omission, left on the table): contradicts ADR-0006 and ADR-0007's own prose,
  contradicts `cook_energy.py`'s pressed-thickness assumption (the lethality numbers in ADR-0015
  would be modelling a physical situation that doesn't exist), and leaves the mouth open for the
  entire ~90 s bake with no compensating benefit — strictly worse on every axis this ADR touches.

**Accepted costs / what this does NOT close.**
- **This is not ADR-0017.** The mouth still opens for ~9 s per cycle, not zero; the bread's own
  face becomes the public-facing seal for the whole bake, which is its own hygiene question
  (already flagged under ADR-0017 option 4); and the 2 mm effective platen contact ring (ADR-0017
  addendum (a)) is untouched — a 2 mm ring still cannot conduction-bake a Ø160 disc regardless of
  when the press happens. ADR-0017 stays **OPEN**; this ADR only fixes the number its options are
  scored against.
- **The PRESS motion itself is new physical work with no bench validation**: how fast a piston
  can close a 60 mm gap on loose hydrated dough without splattering it back out through the mouth
  or the hydration ports is an open engineering question, not asserted here — `press_seconds` is
  a placeholder tied to the existing (also unvalidated) `PRESS_S` sizing assumption, not a
  measured number.
- **The anatomy drawing (`docs/cell_anatomy.svg`) FLAG 2 and panel B caption**, which stated this
  question as open, are updated to point here rather than redrawing the cycle strip with a
  seventh panel — a full redraw is deferred, tracked informally, not a ROADMAP line yet.

**Implementation.** `godot/process_interlock.gd` (`PRESS` state + `press_seconds`, comments on
CHARGE/HYDRATE/COOK/`progress`); `godot/tests/test_interlock.gd`,
`godot/tests/test_spore_hold.gd`, `godot/tests/test_collection.gd` (`press_seconds` added to
short test timings); `scripts/build_model.py` (comment fix); `scripts/actuator_sizing.py`
(`close_travel` replaces the misapplied `stroke`). All six Godot self-test suites re-run and
pass. ROADMAP Now #3 and SAFETY.md's H6 open item updated to the narrower window.

---

## ADR-0020 — Don't retract across a hand: a bounded mouth-clear guard on withdrawal (SF9)
**Date:** 2026-08-04
**Status:** Accepted (twin logic implemented). Sensor hardware (the mouth presence/safety-edge
device) is shared with SF4 and is still a commissioning choice, same as SF4 itself.

**Context.** ADR-0018 named this gap while closing a different one: *"it is safe to withdraw
[an uncollected batch] precisely because... [but] this does not make retracting safe while a
hand is at the mouth — that is SF4 mouth-presence hardware and is explicitly still open."* The
old code retracted the instant a delivery ended — on a completed present, on an SF4 abort, and
(after ADR-0018) on a proven collection — which is exactly when a hand is most likely to be at
the mouth: reaching in to take the bread, or still touching a batch just condemned. `AWAIT_COLLECT`
made the gap visible; it did not create it. ROADMAP items 4 and 8 tracked closing it.

**Decision.**
1. **New ground-truth input `hand_present`** and gate `retract_clear()` in
   `godot/process_interlock.gd`, reading the same mouth presence/safety-edge sensor SF4's pinch
   cap already needs (H5) — extended to cover withdrawal, not just delivery.
2. **`RETRACT` holds position while blocked, instead of withdrawing anyway.** A stationary
   piston generates no crushing force — the same reasoning `AWAIT_COLLECT` already uses to
   exempt itself from the pinch cap (ADR-0018) applies here identically: waiting is the safe
   move, forcing the motion through is not.
3. **Bounded, and shorter than SF8's window.** `retract_clear_timeout_s := 60.0`, half of SF8's
   120 s collection window, because by the time RETRACT is running the collection question is
   already settled one way or the other: either a person just took the batch (done in seconds —
   they are not still standing there a minute later under any normal case) or the batch was
   condemned with nobody home (nothing to wait for in the first place). A hand still read a full
   minute in is far more likely a stuck sensor or a foreign object than a slow person.
4. **On timeout, alarm — do not force the withdrawal, and do not wait forever.** Escalates to the
   existing `LOCKOUT` state (already signals `ALARM` via `signal_level()`, already means "cannot
   make the line safe automatically, refuse service, alert a human" — no new alarm state needed).
   This is the same shape of choice ADR-0018 made for an uncollected batch (bounded wait, then
   act) and CLEAN_VERIFY already makes for a surface that won't verify clean (bounded retries,
   then LOCKOUT) — SF9 is the same pattern applied to a third kind of "the machine cannot
   currently prove it is safe to keep going."
5. **`LOCKOUT` now has two distinct entry paths and must recover differently**, distinguished by
   `progress` (which LOCKOUT no longer resets to 0 on entry — see below):
   - **Stuck mid-RETRACT (SF9):** `progress > 0`. Recovers automatically the moment
     `retract_clear()` reads true again and resumes withdrawing — no human required if the
     obstruction was transient (a slow hand, a sensor blip). A repeated flap (clears, blocked
     again) just re-enters LOCKOUT and re-alarms; nothing is served or forced through on a flap.
   - **Stuck at CLEAN_VERIFY (SF2, pre-existing):** `progress == 0` (RETRACT already finished
     before this path is ever reached). Recovers only when a clean verification actually passes
     — needs a real human service call, not just a clear read.
6. **`LOCKOUT` no longer forces `progress = 0.0` on entry.** The old code did this
   unconditionally; harmless for the only path that previously reached LOCKOUT (CLEAN_VERIFY
   failure, where the piston is already at flush by the time it gets there) but wrong for this
   one — an alarm state should freeze the actuator wherever it stopped, not silently command it
   to a position it never reached. This was a latent bug the new entry path surfaced, not a
   consequence of adding one; fixed as part of this change since the old behavior would have
   been actively dangerous applied to SF9's path (claiming, to any observer of `progress`, that
   the piston was flush/sealed when it was actually stopped mid-bore with a hand at the mouth).

**Why (design).** This mirrors HiveCell's foundational rule, applied to the one motion in
SeedCell that most resembles it: HiveCell never *moves* until a space is proven empty; here, the
piston never *withdraws* until the mouth is proven clear. Every other SF in this repo bounds a
*wait* (SF7's hold, SF8's collection window) because the thing being waited on is itself decaying
(spore risk, street exposure). This one is different: a stationary piston creates no new hazard
by waiting, so there is no safety reason to ever force the motion — only an availability reason
to eventually stop waiting quietly and tell a human, which is what the timeout is for.

**Rejected alternatives.**
- *Retract anyway after a short grace period*: defeats the entire purpose of a presence guard —
  the failure mode being defended against (a hand caught by the closing/withdrawing motion) is
  exactly what this would eventually do on a delay.
- *Wait forever, no timeout*: a stuck-faulted sensor (or a genuinely abandoned object at the
  mouth) then parks the machine out of service permanently with no signal to anyone — an
  availability failure indistinguishable from a silent hang, which is worse than an alarm.
- *A new dedicated alarm state instead of reusing `LOCKOUT`*: `LOCKOUT` already means exactly
  "cannot make safe automatically, refuse service, alert a human" and already drives
  `SignalLevel.ALARM`. A second state with identical external meaning would be duplication, not
  rigor — the two recovery paths are enough of a distinction to track via `progress` without a
  new enum value.

**Accepted costs / what this does NOT close.**
- **Sensor hardware is not chosen.** Same open item as SF4 generally (ROADMAP item 8): pick and
  qualify the presence/safety-edge device, confirm it reads reliably across the retract travel,
  not just at the mouth plane.
- **`retract_clear_timeout_s := 60.0` is an engineering judgement, not a measured number** — same
  caveat ADR-0018 recorded for its own window, and for the same reason (no real siting data yet).
- **LOCKOUT's two recovery paths are distinguished by reading `progress`, an implicit signal, not
  an explicit reason field.** This is consistent with this twin's existing minimal-state style
  (e.g. `_batch_condemned` is reused the same way across states) but means a third LOCKOUT entry
  path, if one is ever added, cannot reuse this trick and would need an explicit discriminator.
- **This does not touch `mouth_open()`**, which stays scoped to `PRESENT`/`AWAIT_COLLECT` for
  SF8/H6 purposes (ADR-0018). A RETRACT blocked by SF9 has the mouth physically ajar too, but
  that is a separate bookkeeping question this ADR does not decide.

**Implementation.** `godot/process_interlock.gd` (`hand_present`, `retract_clear_timeout_s`,
`retract_clear()`, `RETRACT`/`LOCKOUT` state logic); `godot/tests/test_interlock.gd` (scenarios
S6, S7). SAFETY.md gains **SF9** and an updated H5 row; ROADMAP items 4 and 8 updated.

---

## ADR-0021 — Remove the mouth die: the bore ends in a plain open cylinder
**Date:** 2026-08-05
**Status:** Accepted (CAD, drawing and export updated). Hands ADR-0017 a **harder** problem, and
does not pretend otherwise.

**Context.** `MouthDie` was a hardened Ø180/Ø156 ring standing 10 mm proud of the public wall,
present since the first commit. It was never justified in an ADR of its own — it arrived with the
initial geometry and accumulated three jobs by assertion. Reviewing it against the decisions that
came later, none of the three survives:

1. **"Peeler" — shears the bread's rim so it releases from the piston face.** This duplicates
   **ADR-0008**, which is an entire decision dedicated to making the bread leave *by itself*
   (low-adhesion surface + sacrificial flour boundary layer + a lean formula that shrinks and
   self-releases "before the piston even ejects it"). If ADR-0008 holds, the peeler is redundant;
   if it does not, a shearing ring is not the rescue — the machine has a much larger problem
   (ADR-0011, the master variable). Worse, shearing a Ø160 disc down to Ø156 **generates trimmings
   at the public face every cycle, and nothing in the repo says where they go.** A crumb stream
   outside the cleanable volume is the opposite of what ADR-0010 is for.
2. **Second cook platen** — ADR-0007's "heated bore-end/die". Already disproven by ADR-0017's
   own addendum: the disc overlaps the die by 2 mm radially, and **a 2 mm contact ring cannot
   conduction-bake a Ø160 disc.** This job was fictional before this ADR touched it.
3. **Front mechanical hard stop** — the physical guarantee that a runaway drive cannot fire the
   piston into the street. **This one is real and is retained**, but it does not need to live in
   the aperture. It moves to **drive-side mechanical end stops** in the service plant, which is
   how the sibling project already does it (HiveCell: *"end stops + latch define the travel
   ends"*, *"mechanical hard stops"*). A coupling failure does not defeat this: an undriven
   horizontal piston has nothing pushing it out.

**Decision.** Delete `MouthDie` and its two parameters (`dieThk`, `deliveryDia`). The bore ends
in a **plain open cylinder at the wall plane**. Forward travel is limited to X=0 by a drive-side
end stop, outside the food path.

**Why this is better, not merely simpler.**
- **ADR-0001 becomes literally true.** "The piston face *is* the flush public wall — no separate
  door or shutter" was, geometrically, false: a ring stood 10 mm proud of that wall, so the public
  face was a 10 mm-deep, Ø156 well with the piston recessed at the bottom of it. Now the face
  really is the wall.
- **The serving is offered instead of buried.** A 10 mm-proud ring against an 8 mm bread left the
  flatbread **recessed 2 mm inside a hole** — a person had to reach into a Ø156 aperture and pinch
  a disc they could barely see. With the ring gone, the same stroke leaves the bread **standing
  8 mm proud of a flat wall**, where it can be taken. This is a dignity and accessibility
  improvement, not an aesthetic one, and it is the criterion nobody had been scoring against.
- **Nothing rigid ever crosses the wall plane.** The only thing that protrudes is soft bread, so
  the aperture has no shear edge and the design gains no new pinch geometry. `build_model.py`'s
  report now asserts this (`protrusion check`: min X over all solids ≥ 0).
- **One less food-contact part**, one less hardened component, one less thing for the scraper
  story to explain — consistent with ADR-0001's "fewest food-contact surfaces possible".

**Rejected alternatives.**
- *Keep the ring and let the piston travel past it to eject fully*: geometrically impossible —
  the piston (Ø160) is larger than the aperture (Ø156) by design, which is exactly what lets the
  face seal the wall. **Full ejection and flush-piston-as-wall are mutually exclusive**; you can
  have one or the other, and the flush wall is load-bearing for ADR-0001.
- *Keep the ring and accept the recessed serving*: preserves a component whose only surviving job
  can be done better elsewhere, at the cost of the delivery being hard to reach.
- *Push a rejected batch out through the mouth onto a street-side grate* (considered while
  discussing waste handling): contradicts ADR-0009's "diverted to waste, **never to the mouth**"
  and ADR-0010's "nothing waste-related on the public face". Not adopted.

**Accepted costs / what this does NOT close.**
- **It makes ADR-0017 harder, and that is the honest headline.** The die was the last nominal
  occupant of the bore end. With it gone there is *definitively* nothing there: the bake is
  **one-sided** (only the piston face is a platen) and the dough's outer face is **open to the
  street for the whole cook**. ADR-0017 is no longer "how do we close a Ø156 hole" — it is
  "what belongs at the bore end at all". See its second addendum, below.
- **Rim quality and the running gap are now unmanaged.** The die trimmed the disc's outer 2 mm,
  which incidentally cleaned up any dough extruded into the 2 mm running clearance under forming
  pressure. That job now falls entirely to ADR-0008's self-release and SF3's scraper lips.
  ADR-0010 already flags "confirm the scraper actually clears crumbs to waste and not into the
  running gap" — this raises the stakes on that bench item rather than adding a new one.
- **8 mm of protrusion is asserted to be graspable, not measured.** It is a large (Ø160) but thin
  disc standing off a flat wall. That should be checked with real hands, including someone with
  limited dexterity, before the geometry is frozen.
- **Self-release becomes load-bearing with no mechanical backup.** ADR-0011's bench test was
  already the master variable; it is now also the only thing that gets the bread off the face.

**Implementation.** `scripts/build_model.py` (part + params removed, docstring rewritten, new
`protrusion check` assertion); `scripts/export_blender.py` (`die_thk_m` / `delivery_dia_m` dropped
from the manifest); `docs/cell_anatomy.svg` (die removed from the longitudinal section; mouth
detail view C redrawn as the delivery pose; legend item 4, cycle panels 3–4, FLAG 1 and key dims
rewritten); `docs/SAFETY.md`, `README.md`, `index.html`, `scripts/cook_energy.py`. The Blender
hero render is unaffected — it is built from primitives and never modelled the die.

---

## Component tree (one cell) — reference for ADR-0001

1. Structure/enclosure: fixed heated `CookBarrel` (bore, ≥ 850 mm deep per ADR-0017), wall-interface
   flange & trim, armored public face. (No mouth die since ADR-0021; forward travel is stopped
   drive-side.)
2. Motion/actuation: piston linear drive, bore-as-guide (no external rails, HiveCell ADR-0007
   lesson), actuator-to-piston coupling, mechanical hard stops, passive flush latch; **anvil drive**
   (retraction mechanism TBD — ADR-0017).
3. Food path (kept minimal): `DryStorage` hoppers + dosers, oil reservoir, `HydrationRing`
   (injection mix, ADR-0006), the bore + piston face + **retractable heated anvil** (form + cook,
   ADR-0017), `WasteChute` (divert).
4. Sensing/safety/control: SF1 diverse lethality probes (2× core thermocouple + IR pyrometer
   + F-value integrator, ADR-0009), SF6 hopper spoilage sensors, piston position + limits,
   **anvil position + limits**, mouth presence + safety edge (SF4), delivered-surface thermometer
   (burn guard), rated safety controller.
5. Services: power, water in + wash drain, `SterilizeRing` (steam/hot-water), `HotAirKnife`
   (dry), heaters (griddle + face + **anvil face**), status beacon (SF5).
6. Cleaning subsystem (ADR-0010): piston scraper lips (SF3) + SterilizeRing + HotAirKnife +
   reused bake heat; all service-side; nothing on the public face. **Anvil face must retract
   before the cleaning stroke begins** (ADR-0017 open item).
7. User interface: exterior availability/status beacon (SF5), privacy-preserving ration
   camera (ADR-0013), delivery aperture (the mouth), no buttons/handles.

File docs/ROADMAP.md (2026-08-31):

# SeedCell — Roadmap

At this stage the highest-value work is **reducing uncertainty**, not more CAD. SeedCell
is design + first-order simulation; the numbers that matter (residue, cook lethality,
clean log-reduction) are estimated, not measured. This file is versioned narrative; live
state belongs in GitHub Issues once the repo is public.

## Now (high priority)
| # | Item | Area | Why |
|---|---|---|-----|
| 1 | Residue + release bench test | food/hygiene | The master variable (ADR-0011); gates SF2, SF3, the surface + formula. See below. |
| 2 | Clean-verify sensor survey | sensing | The hardest open problem: prove a food surface is clean, every cycle, unattended (SF2). |
| 3 | **Implement ADR-0017 in CAD + twin** (anvil + bore depth) | safety/sim | ADR-0017 decided 2026-08-11: retractable heated anvil at ≥ 850 mm depth. Bore geometry not yet frozen. Needs `bakeDepth` in `build_model.py`, BAKE + OPEN_ANVIL states in `process_interlock.gd`, redrawn `cell_anatomy.svg`, and a decided anvil retraction mechanism. |

## Next (medium priority)
| # | Item | Area | Why |
|---|---|---|-----|
| 5 | Jet-hydration dough trials | food | Does blade-free injection mixing (ADR-0006) give uniform dough? Research question #2. |
| 6 | Low-adhesion coating durability | materials | PTFE/ceramic under scrape + 230 °C + steam (ADR-0008/0010); couples SF3 wear (H8). |
| 7 | Export pipeline → twin/render | sim | `export_godot.py` + a visual `process_demo` scene (ADR-0014); currently logic-only. |
| 8 | SF4 burn/pinch hardware | safety | Surface-temp cap from burn data; mouth presence + safety edge — the same sensor SF9 (ADR-0020) now also reads through withdrawal. Logic side of retract-with-a-hand-present is closed; this item is the hardware selection both SF4 and SF9 are waiting on. |

## Done
- **Bore end: retractable heated anvil at ≥ 850 mm depth** — **ADR-0017**, 2026-08-11.
  The long-open design fork (closure at the face vs anvil in the bore) resolved: option 2,
  anvil in the bore. ISO 13857 whole-arm reach distance for a Ø164 opening is 850 mm —
  the hot anvil is geometrically unreachable from the street. ADR-0007's two-sided bake is
  restored; H6's mouth-sealed mitigation now holds. Implementation remains (Now #3 above).
- **Removed the mouth die** — **ADR-0021**, 2026-08-05. A Ø156 hardened ring standing 10 mm proud
  of the wall, present since the first commit and never justified by an ADR. Of its three jobs:
  rim-shearing duplicated ADR-0008's self-release (and made crumbs at the public face with
  nowhere to go), the "second cook platen" was 2 mm of contact and never worked, and the hard
  stop moved to drive-side end stops (HiveCell precedent) out of the food path. Removing it made
  ADR-0001's flush wall literally true and turned the serving from **2 mm recessed inside a hole**
  into **8 mm proud of a flat wall** — an accessibility fix nobody had been scoring for.
  **Deliberately makes Now #3 harder**, and surfaced *delivery ergonomics* as a fifth criterion
  ADR-0017's options had never been judged against.
- **Retract mouth-clear guard / SF9** (was Now #4) — **ADR-0020**, 2026-08-04. The gap ADR-0018
  named: the piston retracted the instant a delivery ended, exactly when a hand is most likely
  to be at the mouth. `RETRACT` now holds position (no crushing force while stationary, same
  reasoning `AWAIT_COLLECT` uses for its own pinch-cap exemption) until the mouth presence sensor
  reads clear, bounded (60 s, half of SF8's window), then alarms via `LOCKOUT` rather than forcing
  the withdrawal through. Fixed a latent bug `LOCKOUT` had carried since it only had one entry
  path before: it unconditionally forced `progress = 0.0` on entry, which was harmless for
  CLEAN_VERIFY failure (piston already at flush) but would have been actively wrong for this new
  path (piston stopped mid-bore). Sensor hardware remains item 8's open question.
- **Press order** (prerequisite to Now #3) — **ADR-0019**, 2026-08-04. Piston presses flush
  right after HYDRATE and holds through COOK — already implied by ADR-0006/ADR-0007's prose and
  `cook_energy.py`'s pressed-thickness assumption, just never implemented. New `PRESS` state in
  `godot/process_interlock.gd`; fixed a real bug it surfaced in `actuator_sizing.py` (press-stroke
  velocity was computed off the full present↔clean stroke, not the actual 60 mm charge↔flush
  travel — force number was fine, power/energy were overstated ~3.5x). Narrows ADR-0017's
  open-mouth window from ~90 s to ~9 s; does not decide ADR-0017 itself.
- **F-value lethality target** (was Now #2) — **ADR-0015**, 2026-08-03. F₇₀ ≥ 13.9 equivalent
  seconds, 7-log *Salmonella*, z = 6.29 °C fitted to the FDA Food Code table; replaces the
  placeholder 75 °C core assumption. `godot/lethality_model.gd` + `tests/test_lethality_model.gd`.
  Note what this did *not* close: probe parts, coldest-point validation and a challenge study
  are still gated hardware work (items 11/12 below), and it surfaced a new hazard — closed below.
- **SF7 bake→serve hold** (was Now #3) — **ADR-0016**, 2026-08-03. *B. cereus* spores survive
  the bake and their toxin is heat-stable, so the control is time: a temperature-gated clock
  accruing only sub-60 °C time, 15-minute default budget, divert-on-timeout.
  `godot/spore_hold.gd` + `tests/test_spore_hold.gd`. Also closed a pre-existing accounting
  gap — a delivery aborted mid-stroke was counted as neither served nor wasted.
- **Uncollected-batch handling / SF8** (was Now #4) — **ADR-0018**, 2026-08-04. The gap ADR-0016
  named. A new `AWAIT_COLLECT` state holds the batch out and `served` now increments only on a
  proven **loaded→empty transition** on the face sensor — so a sensor stuck at either end fails
  to waste rather than manufacturing a phantom serving, and `served` means *a person was fed*
  rather than *the piston moved* (it was the twin's liveness measure, so it was measuring the
  wrong event). The delivery window (120 s) is nested inside SF7's hold budget and bounds
  open-mouth exposure, not food safety. `godot/collection_guard.gd` +
  `tests/test_collection.gd`. **Surfaced a new gap** — retracting while a hand is still at the
  mouth was unguarded, pre-existing — **now closed by SF9 (ADR-0020)**, above.

## Critical-path experiment (not desk work)
**Residue + release is SeedCell's master variable** — the food equivalent of HiveCell's
seal drag. It couples the cleaning method (SF2), the scraper (SF3), the surface material and
the food formula (ADR-0008), and it is currently only *estimated* across a ~1000× range
(`scripts/residue.py`: µg/cm² for a low-adhesion surface + flour boundary layer, vs near
1 mg/cm² for bare hot steel). Everything downstream — whether the machine can be chemical-free
and self-cleaning at all — hinges on which end of that range is real. A ~$150–250 bench
procedure to measure it on a real baked coupon is [`residue_bench_test.md`](residue_bench_test.md).
Keep it visible so the paperwork above never quietly defers it.

## Physical validation & certification (hardware / context gated)
| # | Item | Area | Gate |
|---|---|---|---|
| 9 | Single-chamber cook prototype (form + jet-mix + bake) | food/mech | **proves ADR-0006/0007** — bench rig, no public serving |
| 10 | Clean-cycle log-reduction validation | food-safety | microbiology lab; go/no-go on the no-chemical SF2 claim |
| 11 | Food-safety certification dossier (HACCP + local food law) | compliance | none of this exists yet; required before any real serving |
| 12 | SF1 lethality controller integrity | safety | probe parts + a rated controller + coldest-point validation |

## Explicitly deprioritized
- Cinematic renders / website polish (later; presentation, not de-risking).
- Menu variety / flavour: the mission is a guaranteed nutritious ration, not a restaurant.
- Multi-machine fleet/telemetry: premature before one unit is proven safe.

## Conventions
- Decisions → ADRs in [`DECISIONS.md`](DECISIONS.md). Safety/hygiene changes → [`SAFETY.md`](SAFETY.md).
- Issues tagged `roadmap` + `area:*` (food / food-safety / sensing / materials / sim / safety) + `priority:*`.
- The invariant that gates everything: **a batch that isn't provably cooked AND served on a
  provably clean surface is waste, never a serving** — enforced by `godot/tests/test_interlock.gd`.

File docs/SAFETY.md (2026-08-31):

# SeedCell — Safety & Hygiene (living document)

Food-safety and machine-safety analysis for an unattended public machine that bakes and
serves food. Method: identify hazards (ISO 12100 for the machine + HACCP for the food),
rate risk, assign safety functions. Users are assumed VULNERABLE — food-insecure, possibly
without other options, eating a machine-made ration repeatedly, with no recourse if it
harms them. The primary hazards are therefore FOODBORNE (a bad serving), not just mechanical.

## Design principle (order matters)
1. **PROVE, don't assume** — never present a serving unless the cook kill-step is positively
   proven (SF1) AND the food-contact surfaces were sanitized since the last serving (SF2).
2. **DIVERT on doubt** — a failed cook, failed clean, or any safety-relevant fault sends the
   batch to WASTE and locks the line, never to a person.
3. **DESIGN OUT contact** — the fewest food-contact surfaces possible, self-releasing food,
   dry storage: less to contaminate, less to clean (defense by inherent design).

"Serve it anyway" is NOT a food-safety case. A batch that isn't provably safe is waste.

## Hazard register
Risk = Severity (1-4) × Likelihood (1-4). Severity 4 = serious/widespread illness or injury.

| # | Hazard | Scenario | S | L | R | Required safety function |
|---|---|---|---|---|---|---|
| H1 | Under-cooked serving (pathogen survival) | Kill-step missed; raw/undercooked flatbread served | 4 | 3 | 12 | SF1 proven-lethal cook; divert on fail; never serve on assumption |
| H2 | Cross-contamination via residue | Baked-on film/crumbs from a prior serving smear into the next | 4 | 3 | 12 | SF2 sanitation every cycle; ADR-0008 self-releasing food + low-adhesion surface; SF3 scrape |
| H3 | Spoiled / wet ingredient served | Damp hopper grows mould; spoiled oil | 3 | 2 | 6 | SF6 spoilage lockout (moisture/temp); dry storage (ADR-0012) |
| H4 | Burn at the mouth | Hot piston face / just-baked bread scalds a hand/mouth | 3 | 3 | 9 | SF4 delivered-surface temperature cap; brief present; edge geometry |
| H5 | Pinch / crush at the mouth | Hand reaches in as the piston presents, OR is still at the mouth as the piston withdraws after a delivery | 3 | 2 | 6 | SF4 force cap + safety edge → abort present; **SF9** mouth-clear guard → hold position (never withdraw across a hand), bounded, then alarm (ADR-0020); SF5 slow final approach |
| H6 | Contaminant ingress / tampering | Foreign object, fluid, or vandalism pushed into the mouth | 4 | 2 | 8 | Bore depth ≥ 850 mm (ISO 13857 whole-arm reach distance for Ø164 opening) — the heated anvil is geometrically unreachable from the street (ADR-0017); dough disc plugs the mouth for the full ~90 s bake (ADR-0019 presses right after HYDRATE, ~9 s open window for CHARGE+HYDRATE+PRESS only); no mechanism at the public face (ADR-0001/ADR-0021); presence gate + inspect-on-open. L=2 score confirmed: the "sealed mouth" assumption now holds geometrically. |
| H7 | Cleaning-chemical residue on food surface | A disinfectant (if used) left on the piston face | 4 | 1 | 4 | ADR-0010 thermal+steam, NO per-cycle chemical; if added, a dose+rinse verify + fail-safe |
| H8 | Foreign body from mechanism wear | Coating flake / seal fragment ends up in the bread | 3 | 2 | 6 | Food-grade materials; SF3 wear budget; inspection; frangible-part exclusion from food path |
| H9 | Allergen exposure | Wheat/legume allergens inherent to the formula | 3 | 3 | 9 | Clear fixed labelling at the machine; formula is fixed + published (facility-level) |
| H10 | Spore outgrowth in a held batch | *B. cereus* spores survive the bake (H1's kill-step cannot reach them) and outgrow while a finished batch waits; the emetic toxin is heat-stable, so no later heating can fix it | 4 | 2 | 8 | SF7 bake→serve hold budget, temperature-gated, divert on timeout (ADR-0016) |
| H11 | Uncollected serving | Nobody takes the presented batch (the requester left, was frightened off, or dropped it): the mouth stays open on it, a person is debited a ration they never received (ADR-0013), and street-exposed food is drawn back through the bore | 4 | 2 | 8 | SF8 collection proof — `served` only on a proven loaded→empty transition; bounded delivery window; condemn + divert on timeout (ADR-0018) |

## Safety functions
Status: **[sim]** = logic implemented and machine-checked in the digital twin — NOT rated
hardware, no performance-level claim yet. **[decision]** = chosen, not yet implemented.
**[cad]** = geometry/space-claim in the FreeCAD model. **[todo]** = not started.

- **SF1 Cook lethality (primary)** — *[sim: fail-safe voting]* every serving must positively
  prove an accumulated time-temperature lethality (F-value) before it may be presented.
  Diverse-redundant channels (2× core thermocouple + IR surface pyrometer + independent
  F-value integrator), AND-toward-safe, fault-is-unsafe. Fault or unproven ⇒ divert to waste.
  Architecture + logic in **ADR-0009** / `godot/cook_lethality.gd`. The target is now set
  (**ADR-0015**): **F₇₀ ≥ 13.9 equivalent seconds, z = 6.29 °C** — a 7-log *Salmonella*
  reduction fitted to the FDA Food Code 3-401.11 table, integrated from the **coldest**
  core probe, with no credit below 60 °C and no carry-over between batches
  (`godot/lethality_model.gd`). Probe parts, coldest-point placement and challenge-study
  validation remain TBD. This is the food analog of HiveCell's SF1 occupancy detection.
- **SF2 Surface sanitation (primary)** — *[sim + decision]* the food-contact surfaces (bore +
  piston face) must be scraped, sanitized, and verified clean after every serving before the
  next charge. Unverified ⇒ re-clean; repeated failure ⇒ LOCKOUT (no service). Method in
  **ADR-0010** (scrape + steam + reused-heat sterilize + dry); verification sensor TBD.
- **SF3 Contamination barrier / scraper seal** — *[cad: gap-fill + drag budget]* circular
  scraper lips on the piston bridge the running gap, wipe the full bore perimeter each
  stroke (the syringe-native squeegee, ADR-0010 step 1), and separate the public mouth side
  from the sealed service side. Aggressiveness couples to residue (ADR-0011) and wear (H8) —
  **measure residue/release before fixing lip count + interference** (`docs/residue_bench_test.md`).
- **SF4 Burn + pinch guard (public safety)** — *[sim: abort logic]* the present stroke is
  gated on a touch-safe delivered-surface temperature (burn, H4) AND no over-limit mouth
  force / no reach-in (pinch, H5). Either unsafe ⇒ abort the present and retract; never push a
  serving through a hand or serve a scalding surface. `mouth_safe()` in
  `godot/process_interlock.gd`; force cap + presence sensor + surface thermometer TBD.
- **SF5 Motion signalling + soft profile** — *[sim]* status beacon (green ready / blue working
  / amber presenting / orange closed / flashing-red alarm) + soft-start/stop + speed-limited
  final approach at the mouth (`godot/soft_profile.gd`, shared unchanged with HiveCell).
  Defense-in-depth only — never a primary safeguard.
- **SF6 Ingredient integrity / spoilage lockout** — *[decision]* hopper moisture + temperature
  monitoring refuses to charge from a wet/spoiled hopper (H3), fail-safe like an SF1 sensor
  fault. Dry storage (ADR-0012) makes spoilage unlikely; the lockout catches seal failure.
- **SF7 Bake→serve hold (primary, spore control)** — *[sim: gate logic]* SF1 proves the batch
  was *cooked*; SF7 proves it has not since sat long enough for the ***B. cereus* spores that
  survived that cook** to outgrow. Their toxin is heat-stable, so this is the one food hazard
  that no amount of heat can fix after the fact — the control is **time**. A temperature-gated
  clock accrues only sub-60 °C time from end-of-bake; past the budget (default **15 min**,
  a facility-level parameter) the batch is diverted to waste, never served. A dead thermometer
  accrues risk rather than pausing the clock. **ADR-0016** / `godot/spore_hold.gd`. The batch
  left uncollected at the mouth — the case SF7 did not cover — is now **SF8**.
- **SF8 Collection proof (accounting + exposure)** — *[sim: transition-proven]* a serving is not
  *served* until a person has positively **taken** it. Collection is read as a **transition**
  (the face seen carrying the batch, then seen empty), never as a level, so a sensor stuck at
  either end fails to waste instead of manufacturing a phantom serving. The whole delivery —
  stroke plus the `AWAIT_COLLECT` wait — is bounded by a window (default **120 s**); on expiry
  the batch is withdrawn, condemned and diverted, never re-offered. The window is nested inside
  SF7's hold budget, so the food-safety bound always dominates; what SF8 bounds is the open-mouth
  exposure (H6) and one person's ability to hold the machine out of service. Sensor: loss-of-mass
  on the actuator force channel SF4 already needs. **ADR-0018** / `godot/collection_guard.gd`.
- **SF9 Retract mouth-clear guard (public safety, H5)** — *[sim: gate logic]* the piston must
  never withdraw across a hand. `RETRACT` holds position (no crushing force while stationary,
  the same reasoning `AWAIT_COLLECT` uses for its pinch-cap exemption) until the mouth presence
  sensor reads clear, bounded by a 60 s timeout — shorter than SF8's 120 s, because by this point
  collection is already settled one way or the other. On timeout it does not force the withdrawal
  through: it alarms (`LOCKOUT`), the same escalation CLEAN_VERIFY already uses for "cannot make
  safe automatically." Mirrors HiveCell's core rule (never move until proven clear) applied to
  SeedCell's one comparable motion. Sensor: the same mouth presence/safety-edge device SF4 needs
  for the present-stroke pinch cap, read through withdrawal too. **ADR-0020** /
  `godot/process_interlock.gd`.

## FMEA — under-cook / cross-contamination chain (basis for the SF1/SF2 decisions)
Component-level companion to the hazard register: how the cook/clean path can fail and what
reaches a person. Scale 1-4 each (engineering judgment): **S**everity, **O**ccurrence,
**D**etection (4 = hard to detect / nothing catches it). RPN = S×O×D.

| # | Failure mode | Cause | Effect | S | O | D | RPN | Mitigation / decision |
|---|---|---|---|---|---|---|-----|---|
| F1 | Core probe reads false-hot | drift, air gap, mis-seat | a raw batch looks cooked | 4 | 2 | 3 | 24 | diverse redundant SF1 (2nd probe + IR + F-value integrator); AND-toward-safe |
| F2 | F1, but a diverse channel dissents | — | SF1 vote fails → DIVERT to waste, not served | 1 | 2 | 1 | 2 | designed defense-in-depth path (verified in sim) |
| F3 | ALL cook sensing lost / stale | power blip, bus fault, blackout | cannot prove lethality | 4 | 1 | 1 | 4 | fault = unsafe ⇒ no serve (fail-safe); nothing is presented without positive proof |
| F4 | Clean cycle skipped/partial | timing fault, low water, clog | residue smears next serving (H2) | 4 | 2 | 2 | 16 | SF2 verify-clean gate; unverified ⇒ re-clean/LOCKOUT before any charge |
| F5 | Clean verify sensor false-clean | fouled sensor | dirty surface passes | 4 | 1 | 3 | 12 | diverse/periodic-self-test verify; conservative threshold; scheduled human audit |
| F6 | Under-cooked batch reaches the mouth | logic error | a person is served raw food | 4 | 1 | 4 | 16 | **DIVERT-only architecture (SF1)** — PRESENT is unreachable except via a passed lethality check; enforced by self-test |
| F7 | Chemical residue on the face | per-cycle disinfectant not rinsed | chemical ingestion (H7) | 4 | 1 | 3 | 12 | **no per-cycle chemical (ADR-0010)** — thermal+steam only; H7 designed out |

The drivers are **F1** (a plausible sensor lie that only diversity catches) and **F6**
(serving raw — Severity 4, and once served nothing can act, D=4). High severity + no
post-hoc recovery ⇒ they must be *designed out*: SF1's PRESENT state is reachable **only**
through a passed lethality vote, and that invariant is enforced by
`godot/tests/test_interlock.gd` on every push.
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

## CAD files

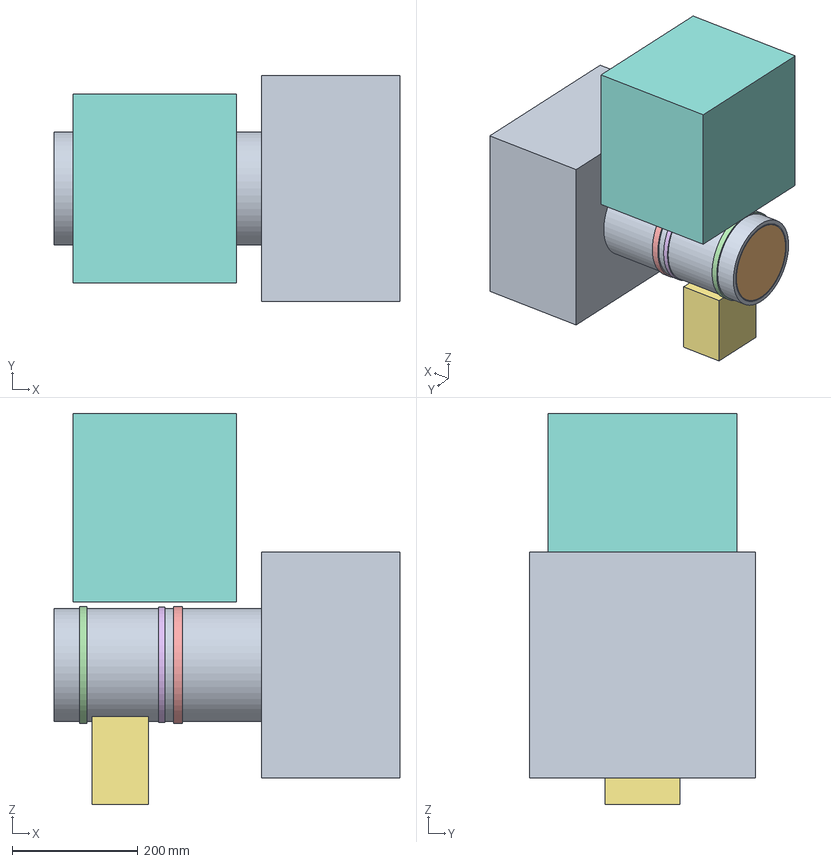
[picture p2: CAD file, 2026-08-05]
cad/SeedCell.FCStd
550.0 x 360.0 x 622.0 mm
CookBarrel
Piston
ScraperSeals
HydrationRing
SterilizeRing
HotAirKnife
WasteChute
DryStorage
ServicePlant

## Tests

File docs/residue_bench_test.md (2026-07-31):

# Residue + release bench test (SF2/SF3) — procedure

> ⚠️ This is a **bench coupon test**, not a machine test. There is no piston and no person
> here — only a heated plate and a dough disc. It measures the ONE number the whole design
> hinges on so the cleaning and scraper systems can be designed against real data.

**Goal.** Measure, on a real baked coupon, (a) the **release force** to detach a cooked
flatbread from a candidate food-contact surface, and (b) the **residue** left on that
surface after one bake + clean cycle. These are SeedCell's master variable (ADR-0011), the
food analog of HiveCell's seal drag: they set whether the machine can be **self-cleaning
without chemicals** (SF2), how aggressive the scraper must be (SF3), and whether the
low-adhesion surface + dry-flour boundary layer + self-releasing formula (ADR-0008) actually
work. First-principles estimate spans ~1000× (`scripts/residue.py`) — far too wide to freeze
a design on.

## 1. What we are measuring, and the units that matter
- **Release stress** `σ_rel` [kPa] — peak force to lift/peel the baked disc off the surface,
  divided by contact area. Feeds `RELEASE_KPA` in `actuator_sizing.py` (eject force).
- **Specific residue** `r` [mg/cm² per cycle] — mass left on the surface after one bake and
  one clean pass, per unit contact area. Feeds SF2 (is it below a safe threshold every
  cycle?) and the cross-contamination hazard H2. Also track it as **cumulative** over N
  cycles without a deep clean — the real question is whether it plateaus low or creeps up.

## 2. Bill of materials (~$150–250)
| Item | Purpose | Approx. cost |
|---|---|---:|
| Candidate surface coupons: PTFE-coated, ceramic-coated, bare seasoned stainless | the variable under test | $40 |
| Hot plate / griddle with a set-point to 250 °C | the platen | $50 (or reuse a kitchen griddle) |
| Kitchen scale, 0.01 g resolution | residue mass (before/after) | $25 |
| Force gauge or hanging scale (peak-hold), 0–50 N | release force | $30 |
| Flours per the blend + a fine flour duster | dough + boundary layer | $15 |
| IR thermometer | verify surface temp | $20 |
| Scraper blade + small steam source (kettle) | the clean pass | $20 |

A digital kitchen scale + a fishing scale are valid low-cost substitutes for lab gear.

## 3. Procedure & data recording
1. **Weigh** the clean, dry coupon (`m0`).
2. **Boundary layer:** for "dusted" runs, dust the coupon with a metered dry-flour film;
   for "bare" runs, skip it (the control).
3. **Bake:** deposit a fixed dough charge (per `dosing.py`), press to ~8 mm, hold both-sided
   contact at the test temperature for the cook time from `cook_energy.py`.
4. **Release:** attach the force gauge to the cooled-just-enough disc and record the **peak**
   force to detach it; note whether it self-released before any force (σ_rel ≈ 0).
5. **Clean:** one representative pass — scrape + a few seconds of steam + a wipe (or dry
   heat-hold, to test the reused-heat sterilize step). No chemicals in the baseline.
6. **Weigh** the coupon again (`m1`). Residue mass = `m1 − m0`; `r = (m1 − m0) / area`.
7. **Repeat 3–6** on the SAME coupon for ≥20 cycles without a deep clean, logging `r`
   cumulatively — this is the plateau-vs-creep question that decides SF2.

Data table template:

| run | surface | boundary | hydration | σ_rel (N) | area (cm²) | **σ_rel (kPa)** | Δm (mg) | **r (mg/cm²)** | cum r |
|-----|---|---|---|---|---|---|---|---|---|

Keep everything else fixed within a run so each row isolates one variable (surface,
boundary layer, or hydration).

## 4. Feed the result into the analysis
```sh
python3 scripts/residue.py                    # compare measured r to the first-order bracket
SCRAPER_DRAG_PER_M=<n> flatpak run --command=freecadcmd org.freecad.FreeCAD \
    scripts/actuator_sizing.py                # re-budget eject/scrape force at the measured value
```

## 5. What the number decides (acceptance thresholds)
| Measured residue trend | Consequence |
|---|---|
| `r` plateaus low (≲ few µg/cm², cum stable) | **Go:** chemical-free self-cleaning (SF2) via scrape+steam+heat is viable; freeze the low-adhesion surface + flour boundary layer (ADR-0008/0010). |
| `r` moderate but creeping | Add a periodic (not per-cycle) deeper clean; revisit scraper interference/lip count (SF3); still no per-cycle chemical. |
| `r` high / baked-on film | **Rework:** the no-chemical claim fails — either change surface/formula, or add a per-cycle chemical step (and then own hazard H7 + a rinse-verify). Re-open ADR-0010. |

## 6. Test safety
Bench hazards only: a hot plate (burns — gloves, eye protection), steam, and food handling
hygiene (this is a food test — clean gear, fresh flour). There is no piston and no high force
here, only a coupon and a dough disc.

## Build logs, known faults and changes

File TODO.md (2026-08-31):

<!-- BOARD
url: https://claude.ai/code/artifact/95ab8c92-9521-4003-a6eb-bbed1aa530a9
headline: On hold since 2026-08-05; the residue/release bench test is the master variable blocking SF2/SF3. ADR-0017 is decided and committed, so the bore geometry is no longer blocked.
now:
- P0 1 residue + release bench test (~$150-250, `docs/residue_bench_test.md`, ADR-0011) — the master variable; gates SF2, SF3, surface + formula
review:
-->

# SeedCell — TODO

**Status: on hold** since 2026-08-05. Narrative + priorities live in `docs/ROADMAP.md`. This file is the actionable checklist the desktop board reads — keep the two in sync.

## Now
- [ ] 1 Residue + release bench test (~$150–250, `docs/residue_bench_test.md`, ADR-0011) — the master variable; gates SF2, SF3, surface + formula
- [ ] 2 Clean-verify sensor survey — prove a food surface is clean every cycle, unattended (SF2)
- [ ] 3 Implement ADR-0017 in CAD + twin — retractable heated anvil at ≥ 850 mm, freeze bore geometry, add `bakeDepth`

## Next
- [ ] 5 Jet-hydration dough trials — does blade-free injection mixing (ADR-0006) give uniform dough?
- [ ] 6 Low-adhesion coating durability — PTFE/ceramic under scrape + 230 °C + steam
- [ ] 7 Export pipeline → twin/render (`export_godot.py` + visual `process_demo` scene, ADR-0014)
- [ ] 8 SF4 burn/pinch hardware — surface-temp cap, mouth presence + safety edge
- [x] Commit the 3 uncommitted files in the working tree (site caption / ADR-0021 follow-up, 2026-08-05)

## Hardware / context gated
- [ ] 9 Single-chamber cook prototype (proves ADR-0006/0007)
- [ ] 10 Clean-cycle log-reduction validation (microbiology lab)
- [ ] 11 Food-safety certification dossier (HACCP + local food law)
- [ ] 12 SF1 lethality controller integrity (probe parts + rated controller)

## Done
- [x] Bore end: retractable heated anvil at ≥ 850 mm (ADR-0017) — 2026-08-11
- [x] Removed the mouth die (ADR-0021) — 2026-08-05
- [x] SF9 retract mouth-clear guard (ADR-0020) — 2026-08-04
- [x] Press order / `PRESS` state (ADR-0019) — 2026-08-04
- [x] SF8 uncollected-batch handling (ADR-0018) — 2026-08-04
- [x] F-value lethality target (ADR-0015) + SF7 bake→serve hold (ADR-0016) — 2026-08-03

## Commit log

2026-07-31 Initial commit: SeedCell — autonomous public food infrastructure
    The food sibling of HiveCell: a public, self-cleaning "food syringe" that bakes a
    fortified flatbread on demand so no one goes hungry for lack of money. Mirrors
    HiveCell's code-first FreeCAD workflow, headless-testable Godot safety twin,
    ADR/SAFETY documentation discipline, and per-medium licensing.
    - Hot-syringe mechanism: one heated piston in a fixed bore = flush wall + cook
    platen + delivery + cleaning interface; food-contact surfaces minimized.
    - Food-safety interlock (Godot): never serve a batch that isn't provably cooked
    (SF1 fail-safe lethality voter) on a provably clean surface (SF2); divert to waste.
    - First-ord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
    [SeedCell.FCStd]
2026-07-31 Add Blender hero-render pipeline + Git LFS for .blend
    - scripts/export_blender.py: FreeCAD -> blender/models/*.obj + scene.json (mm->m).
    - blender/build_scene.py: assembles the wall + mouth + flatbread, lit "night at the
    wall" studio shot, renders assets/hero.png (Cycles CPU). Regenerable; the render
    is an early massing pass, not final hero quality.
    - Git LFS now tracks *.blend (.gitattributes); the pre-push hook calls
    `git lfs pre-push` since core.hooksPath bypasses LFS's own hook.
2026-08-02 Tune hero render to "bread is the hero" + embed in landing page
    The previous hero.png was a rough massing pass: the imported CAD parts
    land at their FreeCAD origins, and the solid Piston sat in the mouth and
    occluded the flatbread, so the shot read as a bronze steel cup on a
    brown blur with no visible bread.
    Rebuild build_scene.py from controlled primitives (sized from scene.json):
    a dark recessed cook chamber, a stainless mouth-die ring, and the golden
    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
2026-08-03 Rework hero: L-shaped anti-reach delivery run, slot bore, WebP web assets
    Rebuild of the Blender hero scene after the 71f295b render was rejected.
    Geometry:
    - Delivery run is an L: a vertical drop chute meeting a horizontal tube
    that a piston pushes the bread along to the public face. REACH_BLOCK =
    0.80 m face->chute so nobody at the mouth can reach in and foul it.
    - Bore section is a 190x190 mm rounded square (r=35). The tall bore lets
    the camera look down ~25 deg, so the bread reads as a full ellipse and
    the sightline clears the floor out to ~0.97 m. SEED_SECTION=round still
    builds the old circular bore.
    - No tray: the bread rests on the bore floor, the only food-contact
    surfa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
2026-08-03 SF1 kill-step target: 7-log Salmonella as an F-value (ADR-0015)
    ADR-0009 fixed the fail-safe voting architecture but left the criterion
    as an acknowledged guess -- "core reaches 75 C". That is not a kill-step:
    it says nothing about hold time, so it cannot tell a core that touched
    75 C for a millisecond from one held there for a minute, and it assigns
    no value at all to a cook that stalled at 68 C. The ft_integrator channel
    had no physics behind it; it was a boolean someone else had to set.
    The target is now F70 >= 13.9 equivalent seconds at z = 6.29 C, a 7-log
    Salmonella reduction. Rather than take a lone literature D-value, both
    constants are fitted to the FDA Food Code 3-401.11 table, whi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
2026-08-03 SF7 bake->serve hold: B. cereus is controlled by time, not heat (ADR-0016)
    ADR-0015 set the SF1 kill-step and, in the same breath, named the hazard
    it cannot reach. B. cereus is endemic to cereal and legume flours; its
    spores survive any bake this machine can perform (spore D-values are
    minutes at retort temperature, against a bake measured in seconds), so
    no accumulated F-value touches them. Worse, the emetic toxin is
    heat-stable -- once produced, re-baking cannot undo it. A machine that
    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
2026-08-04 Add the anatomy drawing and show it on the site
    SeedCell now has the technical drawing HiveCell has: docs/cell_anatomy.svg,
    same file location and the same drawing conventions, embedded in index.html
    as a new #anatomy section between Mechanism and Food.
    Drawn 1:1 from scripts/build_model.py rather than sketched -- one px is one
    mm in the main section, so bore 164, piston 160, wall 8, clearance 2, barrel
    330, charge depth 60, stroke 210 and die 10/156 are all the real numbers.
    Contents: longitudinal section with 12 numbered callouts, an A-A inset (round
    bore through a scraper lip -- the hygiene argument), a B-B inset (sterilize
    zone with the piston stowed), and a three-column legend. The ri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
2026-08-04 File the unsealed-mouth finding as ADR-0017 (open)
    The contradiction the 1:1 anatomy drawing exposed (16e1368) was only recorded
    on the drawing itself and in a commit message, so it was not tracked anywhere
    anyone would look. Filed properly, without deciding it.
    docs/DECISIONS.md — ADR-0017, and the first entry in this log whose status is
    not Accepted: "OPEN, no decision made". Three individually reasonable things
    do not hold together: MouthDie must be an annulus (that is how the bread comes
    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
2026-08-04 SF8 collection proof: presented is not served (ADR-0018)
    Closes the gap ADR-0016 named on its way out: "an uncollected batch left
    presented at the mouth -- that needs a collection sensor and an AWAIT_COLLECT
    state." Until now the interlock did not model collection at all. It incremented
    `served` the instant the present stroke reached full extension and retracted
    immediately, i.e. it assumed collection was instantaneous and always successful.
    Three separate problems were hiding in that one assumption:
    1. ACCOUNTING. `served` is the twin's liveness measure -- the thing that stops a
    trivially-frozen machine from passing its own safety tests -- and it was
    measuring that the piston moved.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
2026-08-04 Rework the anatomy drawing around the mouth; two findings from doing it
    The drawing was legible everywhere except the one place a decision is
    pending: the mouth was a few pixels wide, so ADR-0017 could not actually be
    reasoned about from it. Adds a MOUTH DETAIL band and brings the sheet up to
    date with ADR-0018.
    New in docs/cell_anatomy.svg:
    - MOUTH DETAIL band. View A (sealed, piston flush) and view B (open, piston
    retracted) look at the wall from the street, side by side, so the difference
    between what hazard H6 assumes and what the CAD does is one glance rather
    than a paragraph. View C is the die corner at 8:1 with every part labelled in
    place -- MouthDie, CookBarrel wall, bore,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
2026-08-04 Decide the press order: piston presses flush before COOK, not during it (ADR-0019)
    Resolves the prerequisite ADR-0017's 2026-08-04 addendum named: three artefacts
    disagreed on where the piston sits during CHARGE/HYDRATE/COOK. Turns out this was
    already decided in prose and just never implemented -- ADR-0006 ("the piston then
    presses it") and ADR-0007 ("mix + press + cook ... no transfer") already say press
    comes after hydrate and cook doesn't move the piston again, and cook_energy.py's
    lethality model already assumes an 8mm PRESSED thickness for the whole bake. The
    twin's silence (CHARGE -> HYDRATE -> COOK never touched progress) and
    build_model.py's "charge/cook chamber" comment were the bu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
    [SeedCell.FCStd]
2026-08-04 Close ROADMAP item 4: don't retract across a hand (SF9, ADR-0020)
    ADR-0018 named this gap while closing a different one: the old code retracted
    the instant a delivery ended -- on a completed present, on an SF4 abort, and
    (after ADR-0018) the moment a batch was proven collected -- which is exactly
    when a hand is most likely to be at the mouth. AWAIT_COLLECT made the gap
    visible; it didn't create it.
    Decision: RETRACT now holds position instead of withdrawing regardless. A
    stationary piston generates no crushing force -- the same reasoning
    AWAIT_COLLECT already uses to exempt itself from SF4's pinch cap applies here
    identically, so waiting is the safe move and forcing the motion through is
    no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
2026-08-05 Remove the mouth die: the bore ends in a plain open cylinder (ADR-0021)
    MouthDie was a hardened Ø180/Ø156 ring standing 10 mm proud of the public wall,
    present since the first commit and never justified by an ADR of its own -- it
    arrived with the initial geometry and accumulated three jobs by assertion. Checked
    against the decisions that came later, none of the three survives:
    1. "Peeler" (shears the bread's rim free) duplicates ADR-0008, which is an entire
    decision dedicated to making the bread leave by itself. If ADR-0008 holds the
    peeler is redundant; if it doesn't, a shearing ring isn't the rescue. Worse,
    shearing Ø160 down to Ø156 generates trimmings at the public face eve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
    [SeedCell.FCStd]
2026-08-05 Site: bring the anatomy caption in step with ADR-0021
    The drawing was updated in 6eef946 but the page copy around it still described the
    old framing: the lead called the mouth "not yet sealed", the alt text described view
    C as a sealed/open comparison (it is now the delivery pose at 8:1), and the caption
    presented ADR-0017 as purely a sealing question with no mention of the die removal.
    Restates it as what it now is -- nothing occupies the end of the bore, meaning no
    closure AND no second cooking surface -- and records that removing the ring both
    fixed the delivery (bread proud of a flush wall rather than recessed in a hole) and
    removed the last cover for the missing platen.
    Co-Authored-By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
2026-08-28 Track TODO.md in the repo
    The task list was sitting untracked, so it was never backed up or
    shared with the remote.
    Claude-Session: https://claude.ai/code/session_01XKAtVUJSNUZeTYSPN8WrUj
2026-08-29 docs: add the board block and publish this project's board
2026-08-31 Commit ADR-0017: retractable heated anvil at >=850 mm
    These three doc edits had been sitting in the working tree since
    2026-08-05 and were tracked as a P1 on the board. ADR-0017 moves from
    OPEN to Accepted (option 2: service-side retractable heated anvil at the
    ISO 13857 reach distance), which restores the two-sided bake, makes H6's
    mitigation geometrically true, and unblocks freezing the bore geometry.
    ROADMAP and SAFETY follow it.
    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
